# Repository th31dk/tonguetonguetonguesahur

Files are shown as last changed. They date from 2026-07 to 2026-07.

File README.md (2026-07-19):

<h1 align="center">
    TongueTongueTongueSahur
</h1>
<h4 align="center">
    A Tongue to keep you company during the apocalypse
</h4>

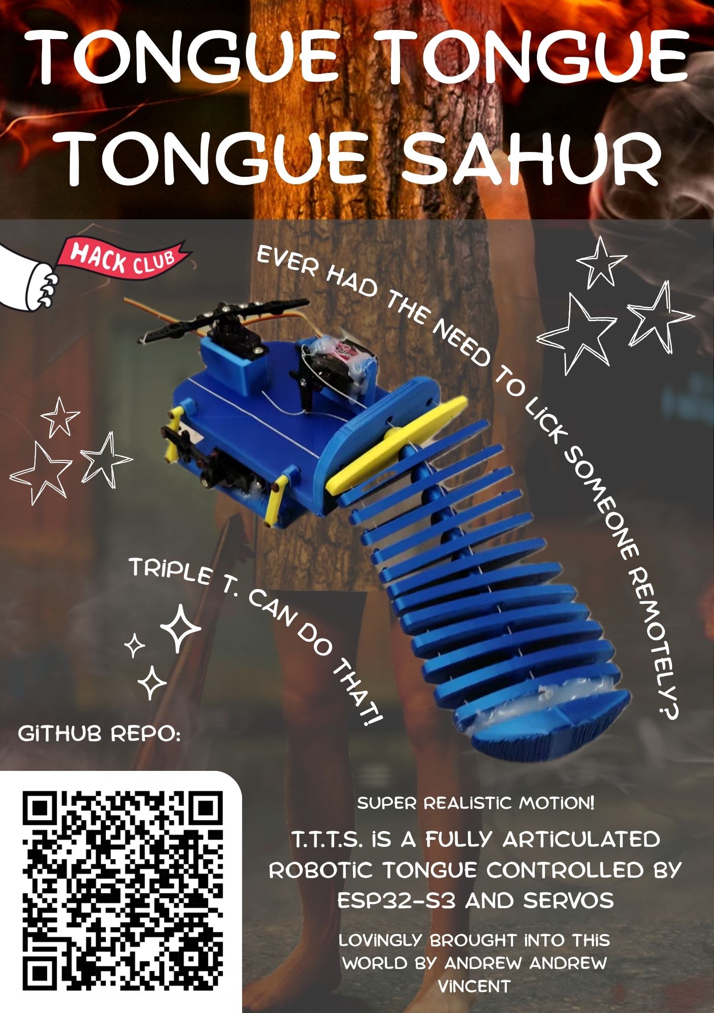
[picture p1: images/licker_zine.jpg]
zine


<h2 align="center">
About this project
</h2>

Tongue Tongue Tongue Sahur is a robotic tongue with three degrees of freedom. Three servos control bending and forwards/backwards movement. Performs pre-programmed routines.

<h2 align="center">
Assembly
</h2>

### Procdure:
 - sort tongue segments according to width, with larger segments closer to base
 - thread ziptie through central hole of segments
 - thread steel fishing line (four in total) through smaller holes and tie to servo
 - base con rod hinges are made from 3D printing filament

Onshape: https://cad.onshape.com/documents/27a7abe3e6ddd3ee8e0502cb/w/bfb3792e82fe8fd004b505b7

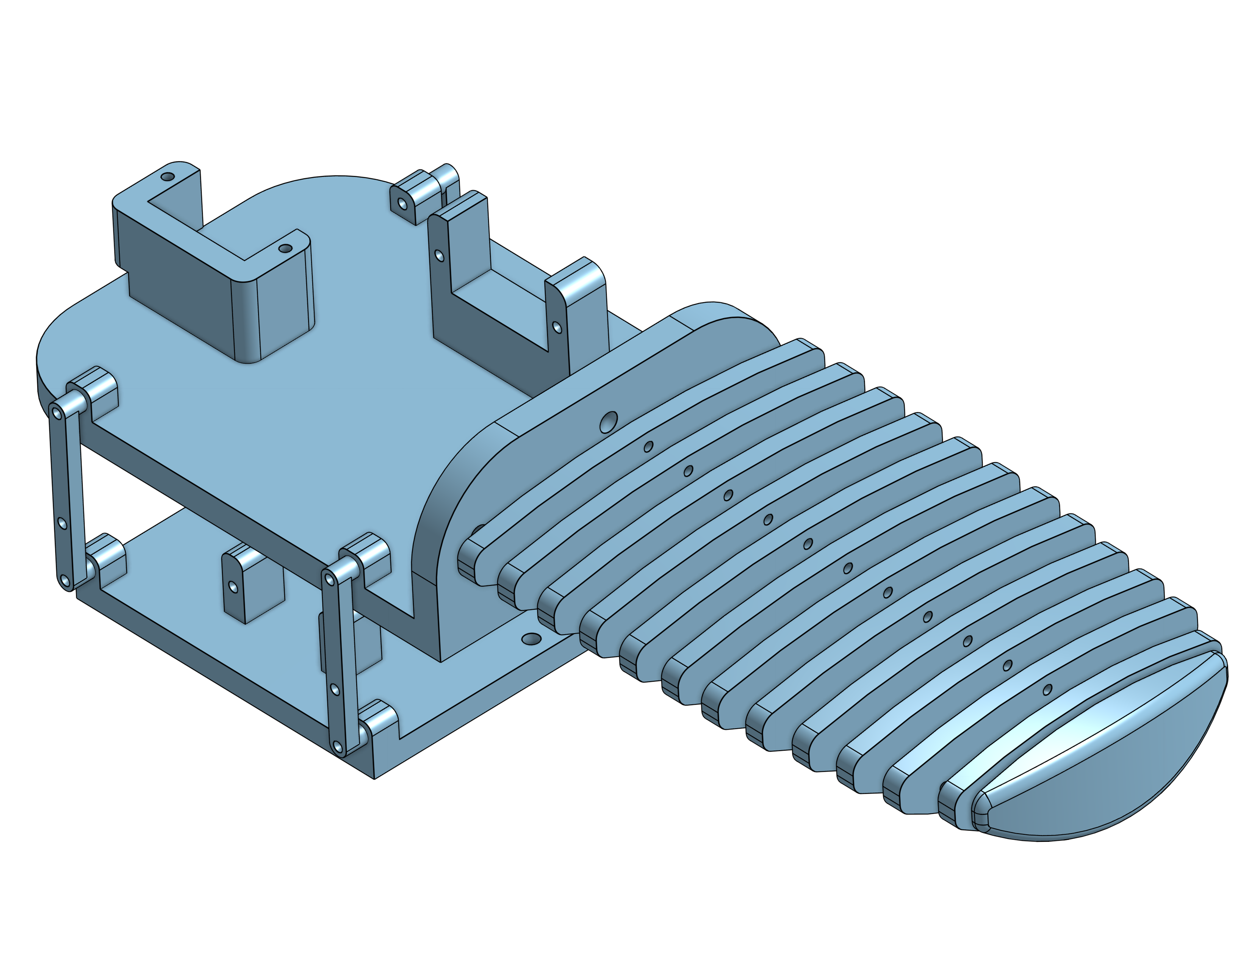
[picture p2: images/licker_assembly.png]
assembly


### Credits
Thank you to:  
[RENRAN SUN](https://github.com/sunrenran)

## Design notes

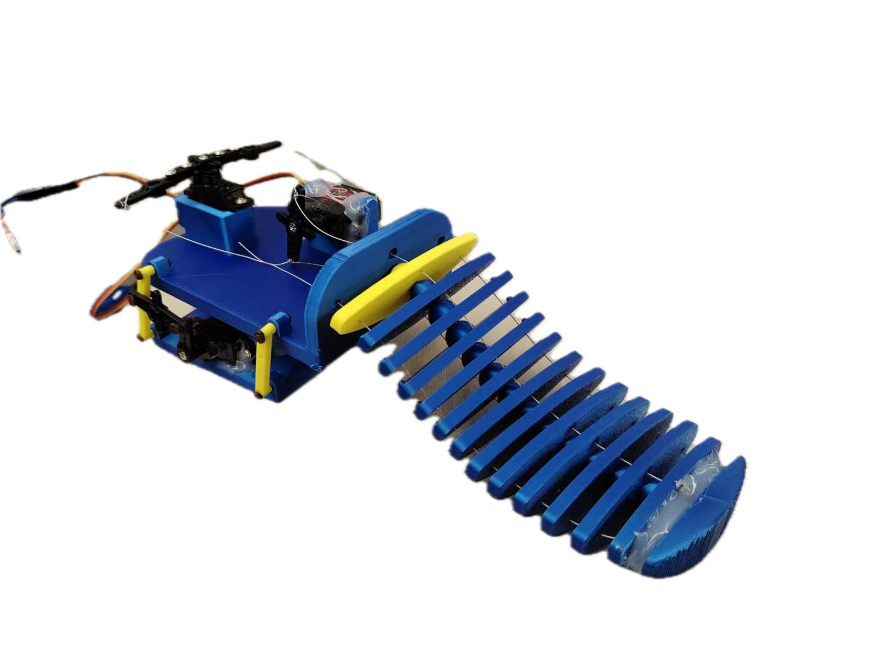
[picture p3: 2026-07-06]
images/Weixin Image_20260706154847_70_12.png

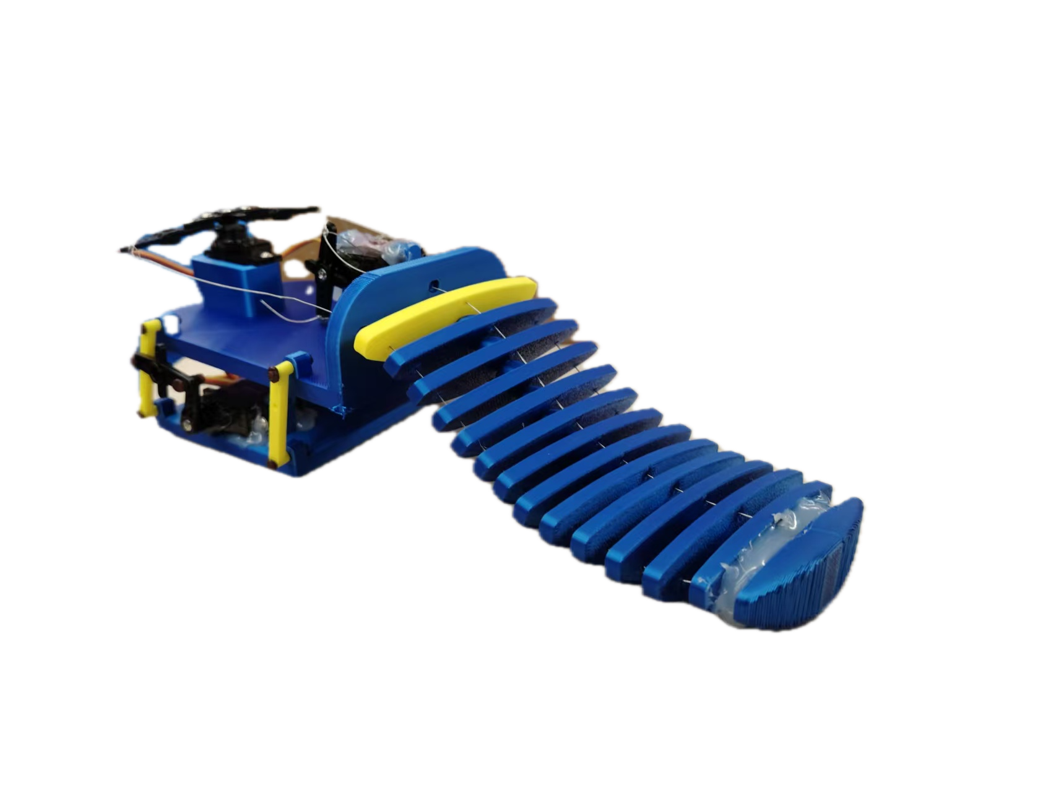
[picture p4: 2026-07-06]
images/Weixin Image_20260706154848_71_12.png

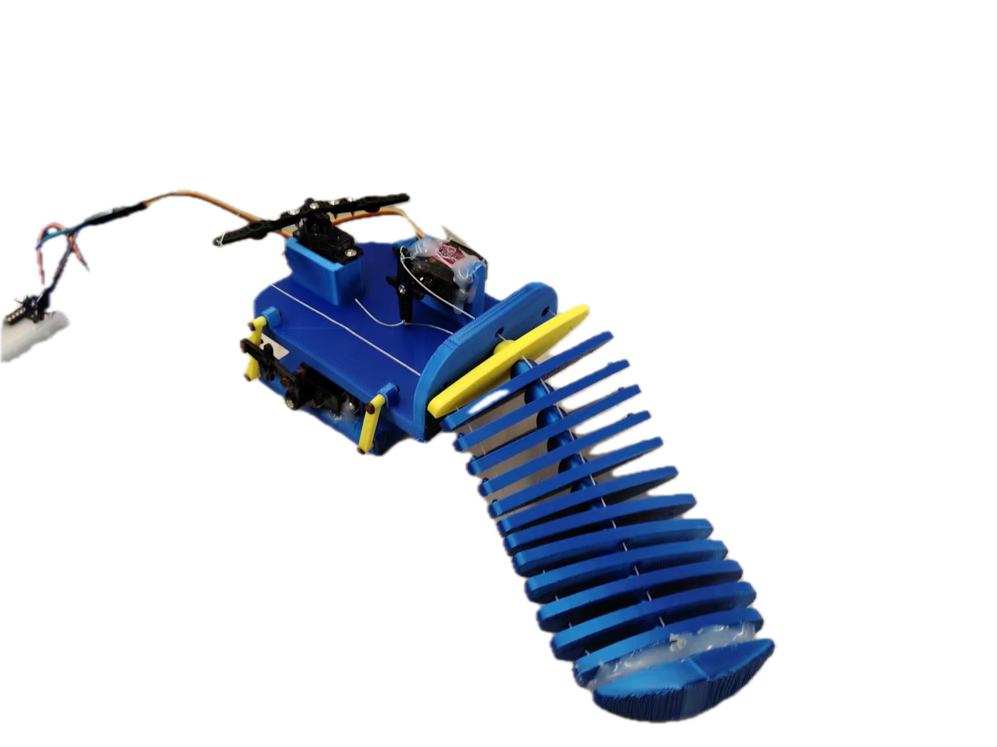
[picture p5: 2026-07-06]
images/Weixin Image_20260706154846_69_12.png

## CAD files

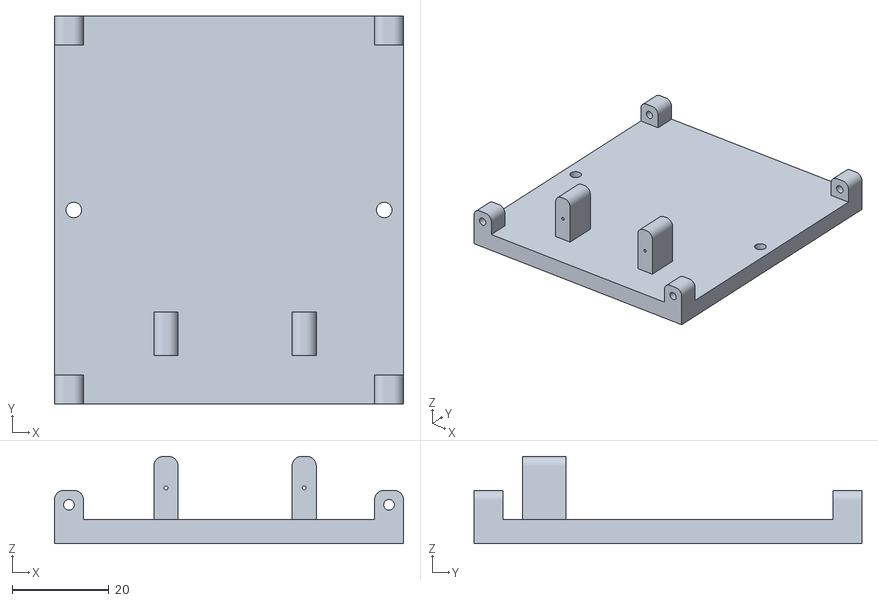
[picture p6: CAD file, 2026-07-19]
3d_printing/base.stl
72.0 x 80.0 x 18.0

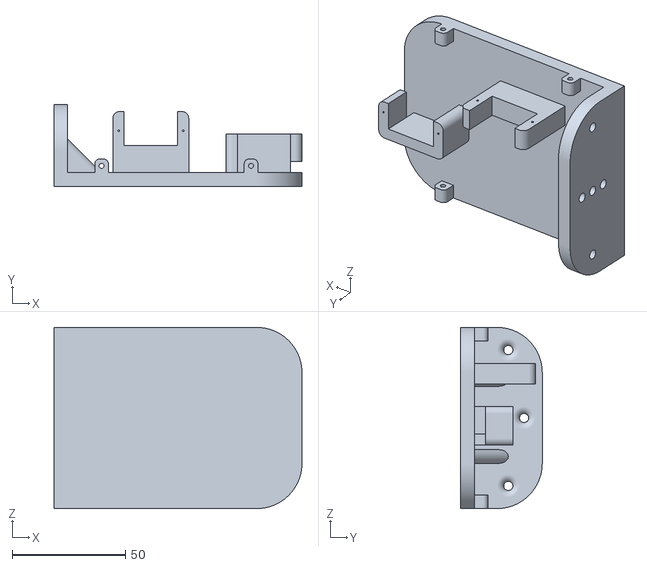
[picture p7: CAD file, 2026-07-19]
3d_printing/tongue_base.stl
109.5 x 36.0 x 80.0

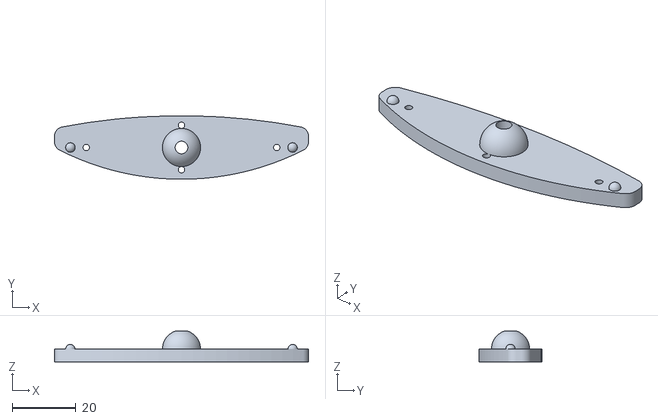
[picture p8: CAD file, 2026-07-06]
3d_printing/seg3.stl
80.0 x 20.0 x 9.66

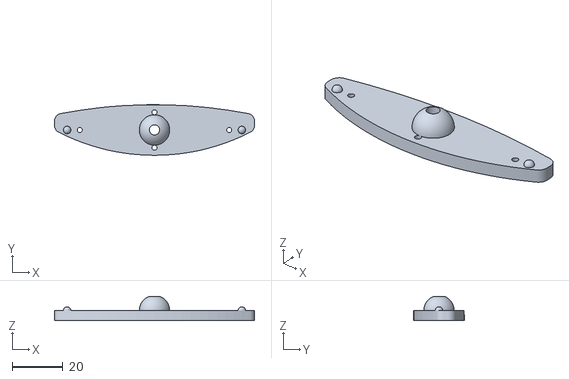
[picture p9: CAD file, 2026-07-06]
3d_printing/seg5.stl
79.0 x 20.0 x 9.66

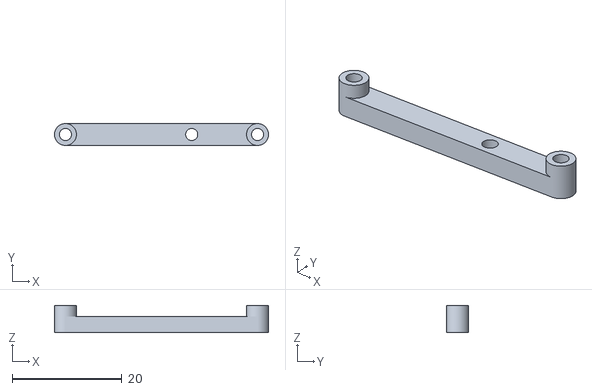
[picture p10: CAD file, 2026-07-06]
3d_printing/con_rod.stl
39.0 x 4.00 x 5.00

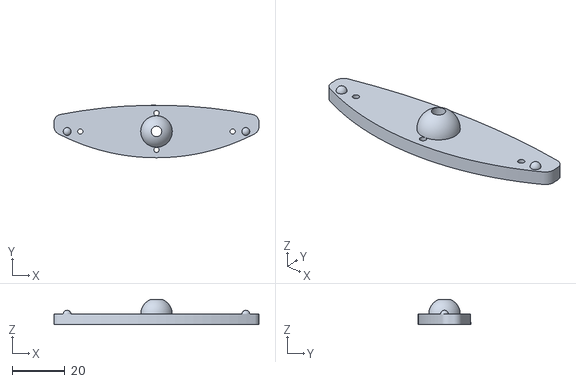
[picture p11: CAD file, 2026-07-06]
3d_printing/seg6.stl
78.0 x 20.0 x 9.66

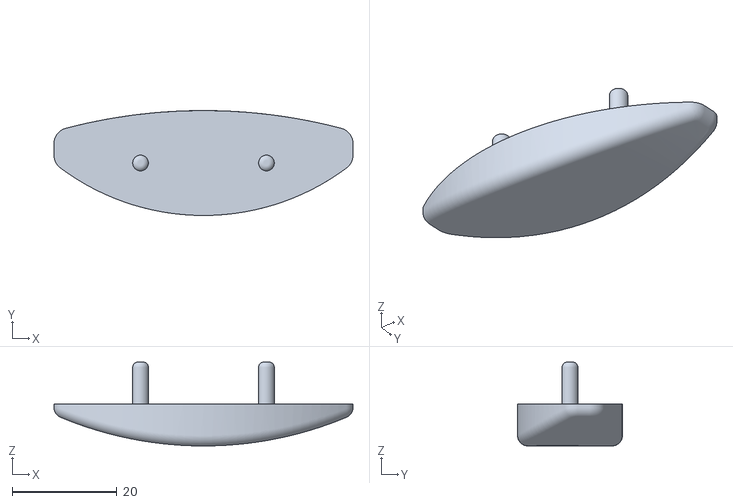
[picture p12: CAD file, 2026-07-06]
3d_printing/tip.stl
57.0 x 20.0 x 16.0

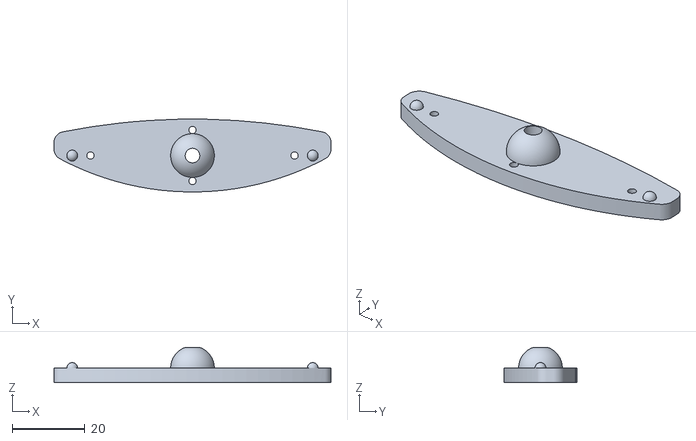
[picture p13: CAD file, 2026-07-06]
3d_printing/seg8.stl
76.0 x 20.0 x 9.66

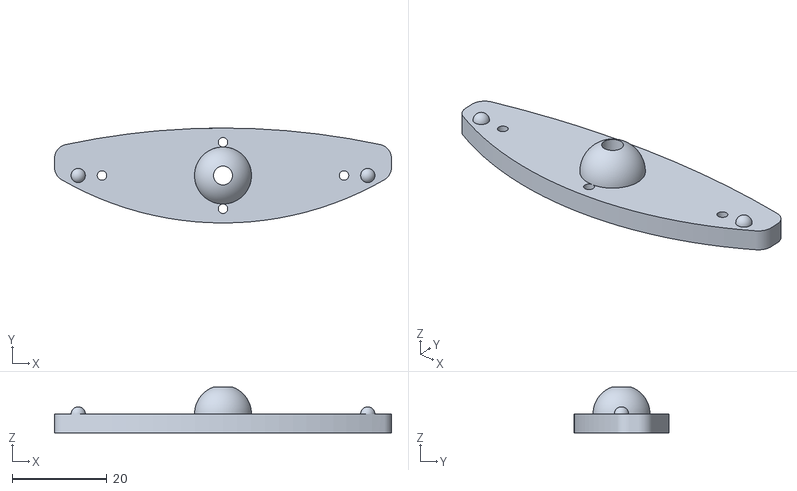
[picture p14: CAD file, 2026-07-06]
3d_printing/seg10.stl
71.0 x 20.0 x 9.66

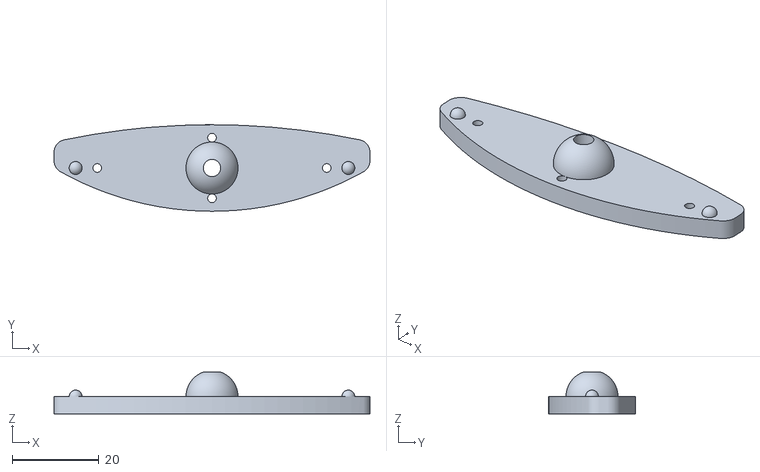
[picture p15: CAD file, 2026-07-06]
3d_printing/seg9.stl
73.0 x 20.0 x 9.66

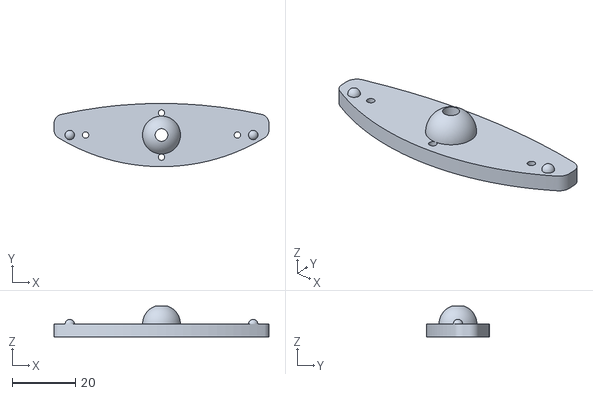
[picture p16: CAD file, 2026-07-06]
3d_printing/seg11.stl
68.0 x 20.0 x 9.66

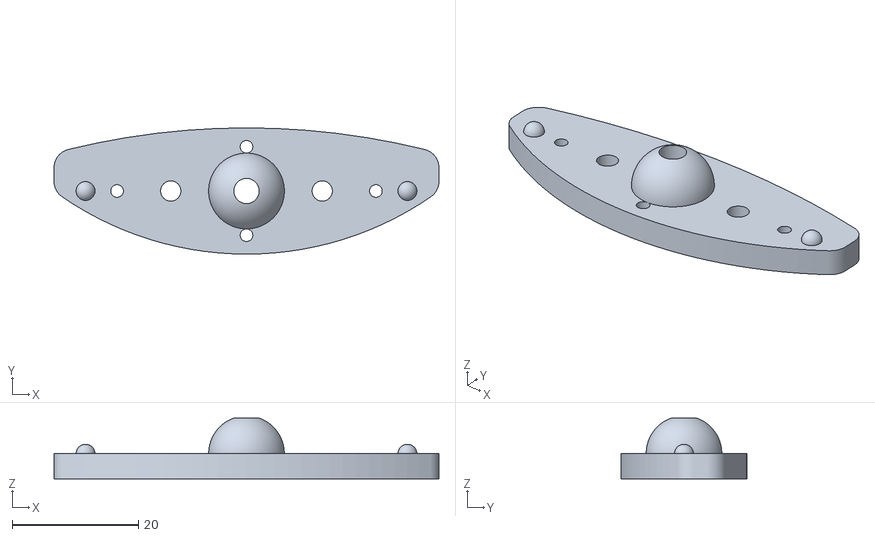
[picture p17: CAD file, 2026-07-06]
3d_printing/seg12.stl
61.0 x 20.0 x 9.66

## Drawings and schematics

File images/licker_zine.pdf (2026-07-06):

# Tongue Tongue Tongue Sahur

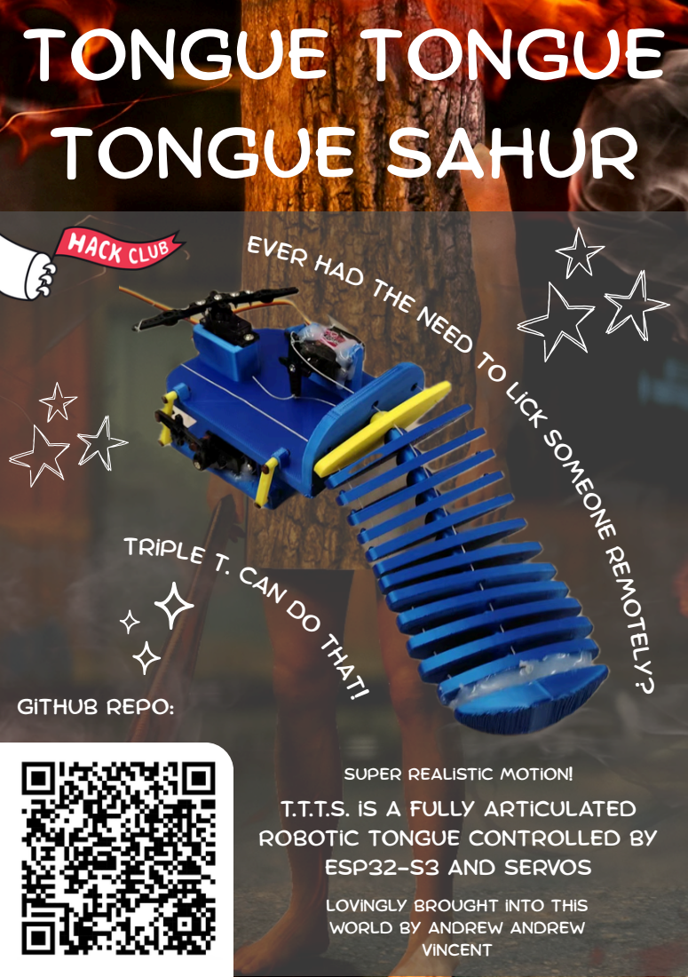
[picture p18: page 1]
remotely?; ESP32-S3 and servos; Vincent; Github repo:

Ever had the need to lick someone

Triple T. can do that!

Super realistic motion!
T.T.T.S. is a fully articulated
robotic tongue controlled by

Lovingly brought into this
world by Andrew andrew

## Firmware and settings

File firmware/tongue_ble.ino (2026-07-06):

/*
  Robotic Tongue - Bluetooth LE Control
  Board: Seeed XIAO ESP32C3
  Servos: 3x SG90
    - Back/forth -> D0
    - Yaw        -> D1
    - Pitch      -> D2

  Control: Bluetooth LE (Web Bluetooth from a browser page - see tongue_controller.html)
  This REPLACES the WiFi web server version - WiFi and BLE both running well
  at the same time is not reliable on this chip, so this sketch only uses BLE.

  Protocol (single BLE characteristic, write-only):
    Browser sends a plain text string, comma-separated, newline-terminated:
      "<yaw>,<pitch>,<backforth>,<circle>\n"
    Each of yaw/pitch/backforth is an integer -100..100 (joystick/slider position).
    circle is 0 or 1 (1 = spin button held/toggled on).

    While circle=1, the ESP32 ignores incoming yaw/pitch and drives them itself
    in a circular sweep. backforth is still taken from input while circling.

  Calibration (from your measured min/max pulse widths, in microseconds):
    Input value +100 maps to the "max" pulse width you measured.
    Input value -100 maps to the "min" pulse width you measured.
    (It's fine that some "min" numbers are numerically larger than "max" -
     that just means that servo's mechanical range is mounted in reverse.)
*/

#include <BLEDevice.h>
#include <BLEServer.h>
#include <BLEUtils.h>
#include <BLE2902.h>
#include <ESP32Servo.h>

// ---------- BLE UUIDs (must match tongue_controller.html) ----------
#define SERVICE_UUID        "12345678-1234-1234-1234-1234567890ab"
#define CHARACTERISTIC_UUID "abcd1234-5678-1234-5678-abcdefabcdef"

// ---------- Pins ----------
const int PIN_BACKFORTH = D0;
const int PIN_YAW       = D1;
const int PIN_PITCH     = D2;

// ---------- Calibration: {pulse at -100, pulse at +100} in microseconds ----------
const int BF_PULSE_MIN  = 2419, BF_PULSE_MAX  = 1010;  // back/forth
const int YAW_PULSE_MIN = 2500, YAW_PULSE_MAX = 1000;  // yaw
const int PITCH_PULSE_MIN = 2240, PITCH_PULSE_MAX = 1000; // pitch

// ---------- Circle mode settings ----------
const unsigned long CIRCLE_PERIOD_MS = 2000; // time for one full circle
const float CIRCLE_RADIUS = 90.0;            // 0-100, how wide the circle sweep is

// ---------- Globals ----------
Servo servoBackForth, servoYaw, servoPitch;
BLEServer* pServer = nullptr;
BLECharacteristic* pCharacteristic = nullptr;
bool deviceConnected = false;

int inputYaw = 0, inputPitch = 0, inputBackForth = 0;
bool circleMode = false;

String rxBuffer = "";

// ---------- Helpers ----------
int valueToPulse(int value, int pulseAtMin, int pulseAtMax) {
  value = constrain(value, -100, 100);
  return map(value, -100, 100, pulseAtMin, pulseAtMax);
}

void applyServos(int yawVal, int pitchVal, int bfVal) {
  servoYaw.writeMicroseconds(valueToPulse(yawVal, YAW_PULSE_MIN, YAW_PULSE_MAX));
  servoPitch.writeMicroseconds(valueToPulse(pitchVal, PITCH_PULSE_MIN, PITCH_PULSE_MAX));
  servoBackForth.writeMicroseconds(valueToPulse(bfVal, BF_PULSE_MIN, BF_PULSE_MAX));
}

void parseCommand(const String& line) {
  // Expected: "yaw,pitch,backforth,circle"
  int p1 = line.indexOf(',');
  int p2 = line.indexOf(',', p1 + 1);
  int p3 = line.indexOf(',', p2 + 1);
  if (p1 < 0 || p2 < 0 || p3 < 0) return; // malformed, ignore

  inputYaw       = line.substring(0, p1).toInt();
  inputPitch     = line.substring(p1 + 1, p2).toInt();
  inputBackForth = line.substring(p2 + 1, p3).toInt();
  circleMode     = line.substring(p3 + 1).toInt() != 0;
}

// ---------- BLE callbacks ----------
class ServerCallbacks : public BLEServerCallbacks {
  void onConnect(BLEServer* server) override {
    deviceConnected = true;
    Serial.println("BLE client connected");
  }
  void onDisconnect(BLEServer* server) override {
    deviceConnected = false;
    Serial.println("BLE client disconnected, restarting advertising");
    BLEDevice::startAdvertising();
  }
};

class CommandCallbacks : public BLECharacteristicCallbacks {
  void onWrite(BLECharacteristic* characteristic) override {
    String value = characteristic->getValue();
    for (size_t i = 0; i < value.length(); i++) {
      char c = value[i];
      if (c == '\n') {
        parseCommand(rxBuffer);
        rxBuffer = "";
      } else {
        rxBuffer += c;
      }
    }
    // Handle commands sent without a trailing newline too
    if (rxBuffer.length() > 0 && rxBuffer.indexOf(',') >= 0) {
      parseCommand(rxBuffer);
      rxBuffer = "";
    }
  }
};

// ---------- Setup / Loop ----------
void setup() {
  Serial.begin(115200);

  ESP32PWM::allocateTimer(0);
  ESP32PWM::allocateTimer(1);
  ESP32PWM::allocateTimer(2);

  servoBackForth.setPeriodHertz(50);
  servoYaw.setPeriodHertz(50);
  servoPitch.setPeriodHertz(50);

  servoBackForth.attach(PIN_BACKFORTH, 500, 2500);
  servoYaw.attach(PIN_YAW, 500, 2500);
  servoPitch.attach(PIN_PITCH, 500, 2500);

  applyServos(0, 0, 0); // center on boot

  BLEDevice::init("TongueBot");
  pServer = BLEDevice::createServer();
  pServer->setCallbacks(new ServerCallbacks());

  BLEService* pService = pServer->createService(SERVICE_UUID);
  pCharacteristic = pService->createCharacteristic(
    CHARACTERISTIC_UUID,
    BLECharacteristic::PROPERTY_WRITE | BLECharacteristic::PROPERTY_WRITE_NR
  );
  pCharacteristic->setCallbacks(new CommandCallbacks());
  pService->start();

  BLEAdvertising* pAdvertising = BLEDevice::getAdvertising();
  pAdvertising->addServiceUUID(SERVICE_UUID);
  pAdvertising->setScanResponse(true);
  BLEDevice::startAdvertising();

  Serial.println("BLE advertising as 'TongueBot' - connect from the controller page");
}

void loop() {
  if (circleMode) {
    unsigned long t = millis() % CIRCLE_PERIOD_MS;
    float angle = (2.0 * PI * t) / CIRCLE_PERIOD_MS;
    int circleYaw   = (int)(CIRCLE_RADIUS * cos(angle));
    int circlePitch = (int)(CIRCLE_RADIUS * sin(angle));
    applyServos(circleYaw, circlePitch, inputBackForth);
  } else {
    applyServos(inputYaw, inputPitch, inputBackForth);
  }
  delay(15); // ~66Hz update, smooth enough for servos
}

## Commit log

2026-07-06 uploaded stls
    [base.stl, con_rod.stl, seg1.stl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]
2026-07-06 added assembly
2026-07-19 fized servo mounts
    [base.stl, tongue_base.stl]
